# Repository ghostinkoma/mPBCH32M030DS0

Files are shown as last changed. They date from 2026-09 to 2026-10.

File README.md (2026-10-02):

# mPBCH32M030DS0 — CH32M030 ユニバーサル・モータードライバ基板

WCH **CH32M030C8U7 (QFN48)** の **DIP-42 MCU モジュール** (ブレッドボード対応) と、差し替え式の **パワー段子基板 (MOSFET ×8)** の 2 枚構成です。
次のモータを駆動します。
USB-C から ESP32-C3 / Arduino のように書き込めて、**USB-PD 充電器 (9〜15V) だけでもモーターを回せます**。
内蔵の電流源・USB-PD・OPA/CMP を使い切る設計です ([内蔵機能の活用検討](docs/advanced_features.md))。

| 駆動対象 | 使うハーフブリッジ | 子基板の出力 | JP5 (子基板) |
|---|---|---|---|
| 3 相モータ (BLDC/PMSM, ホール or センサレス) | HB0〜HB2 (TIM1) | U=OUT0, V=OUT1, W=OUT2 | 1-2 (センサレス 6 ステップは JP7=2-3) |
| フルブリッジ DC ×1 | HB0/HB1 (TIM1) | OUT0-OUT1 | — |
| フルブリッジ DC ×2 | + HB2/HB3 (TIM2) | OUT0-OUT1 と OUT2-OUT3 | 2-3 |
| バイポーラ・ステッピング | A = HB0/HB1, B = HB2/HB3 | A+=OUT0 A-=OUT1 B+=OUT2 B-=OUT3 | 2-3 |

> **ステータス: Rev 0.4 — 回路図 + 2 層基板レイアウト (未試作。全基板の配線完了)**。無保証です (LICENSE)。
> モーター駆動は大電流を扱います。電流制限付き電源で段階的に確認してください。

## Rev 0.4: DIP-42 MCU モジュール + パワー段子基板

- **MCU モジュール** (22.86 × 53.34mm = 2.54mm ピッチで **9 × 21 マス**, 2 層):
  - 左右の端に 1x21 ピンヘッダ ×2 (列間 17.78mm = 0.7in, Raspberry Pi Pico と同じ)。**ブレッドボード (82 × 52mm 等) にそのまま挿せます**。
  - ピンヘッダは **BOTTOM 面に実装し, ピンは MCU と反対側 (下) へ出します**。ブレッドボードや子基板のソケットに挿しても
    USB-C・ボタン・LED が上を向き, USB ケーブルの抜き差しとボタン操作ができます。
    ピン番号は TOP 面 (MCU 側) の外縁, 信号名は BOTTOM 面のシルクに印字しています。
  - USB-C は上端。RESET / USER・BOOT ボタン、センシング選択ジャンパ、**LED (電源 ×3・状態・ゲート ON ×8) はすべてモジュール上面**です。
  - 電圧に依存する部品 (TVS・VBUS 分圧・バルク容量・相電圧分圧) は子基板側にあり、モジュールは共通です。
- **パワー段子基板** A / B / C: 上面の 1x21 ピンソケット ×2 (モジュールと同じ位置・同じピン番号) にモジュールを上から挿します。
  - 左右 2 列のピンで支えるので、嵌合は**左右対称**です (Rev 0.3 の片寄った基板間コネクタによる傾き・接触不良を解消)。
  - MOSFET・シャントなどは子基板の下面 (ヒートシンク側)。LED は置いていません。
  - A/C は下端に電源入力 J3 (2x6) とモータ出力 J4 (2x8)。B は電源 2 本と 4 相出力を **M3 丸端子用の端子台** で受けます。
- 基板面積は Rev 0.3 (60 × 42mm = 2520mm²) に対し、モジュール 1219mm² (**−52%**)、子基板 A/C 1712mm² (**−32%**)、
  子基板 B は丸端子台とヒートシンク固定穴を載せるため 44.6 × 99.5mm (4438mm²) に広げました。
- Rev 0.3 の子基板 D (ピン引き出し) は廃止しました。モジュール単体をブレッドボードに挿せば、全信号にアクセスできます。
- コネクタは USB-C 以外すべて 2.54mm ピンヘッダ、コンデンサは入手性を確認した量産品 (1005〜1206) です。
  構成・寸法・品番の詳細は **[docs/stacking.md](docs/stacking.md)** にあります。

| 子基板 | MOSFET | 寸法 | 用途 |
|---|---|---|---|
| **A** | TPN1R603PL ×8 (30V 1.6mΩ) | 22.86 × 74.9mm | 標準。8〜16V, 約 5A/相 (電源ベタにはんだ盛り 0.3mm で) |
| **B** | TKR74F04PB ×8 (40V 0.74mΩ, TO-220SM(W)) | 44.6 × 99.5mm | **24V 系**, M3 丸端子台 ×6, ヒートシンク固定穴 ×2。`make POWER_STAGE=B`。約 5A/相 (1oz) / **約 7A/相** (はんだ盛り 0.3mm) |
| **C** | MTN2306AN3 ×8 (30V SOT-23) | 22.86 × 74.9mm | 廉価版。約 3A/相 |

| モジュール TOP | モジュール BOTTOM (裏から見た図) | 子基板 A TOP | 子基板 A BOTTOM |
|---|---|---|---|
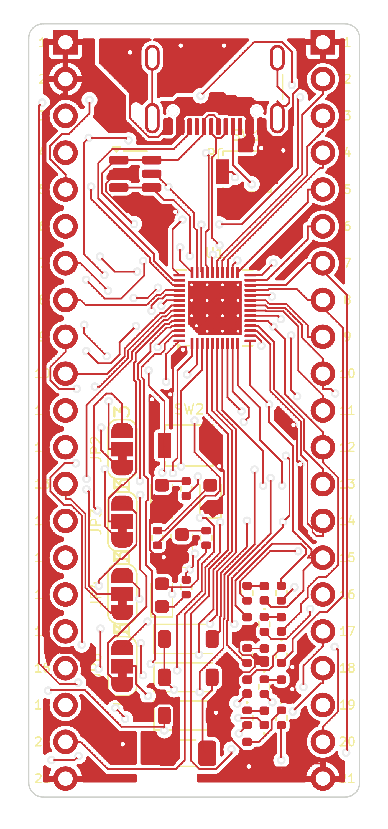
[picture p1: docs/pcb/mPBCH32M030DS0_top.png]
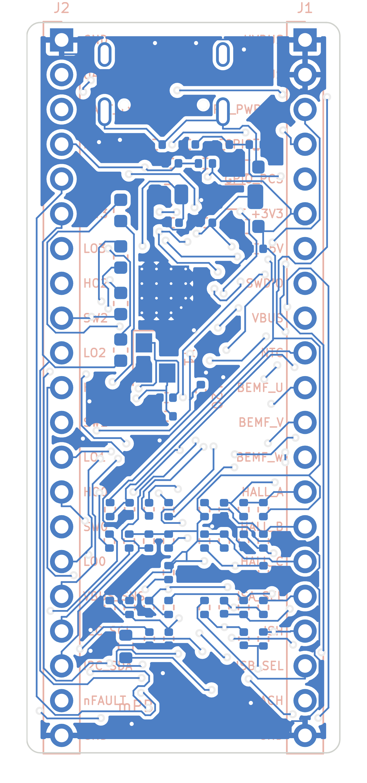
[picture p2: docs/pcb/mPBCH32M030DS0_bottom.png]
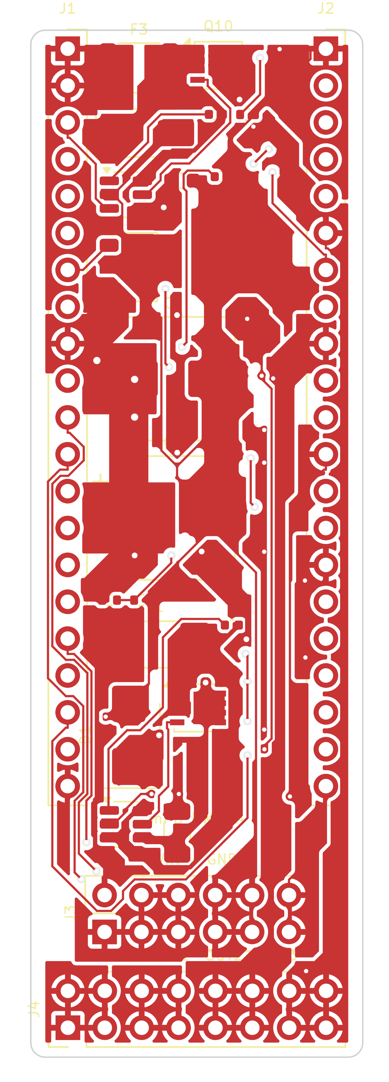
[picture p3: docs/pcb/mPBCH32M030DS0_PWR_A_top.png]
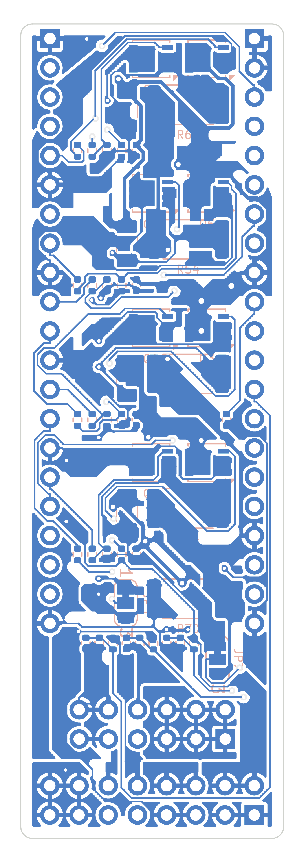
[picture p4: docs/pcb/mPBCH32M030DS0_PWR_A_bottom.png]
|  |  |  |  |

### モジュールのピン配置 (上面から見て USB-C が上, 子基板のソケット J1/J2 も同じ)

| ピン | J1 (左列) | J2 (右列) |
|---|---|---|
| 1 | USB_VBUS | GND |
| 2 | USB_VBUS | UART_RX |
| 3 | PD_PWR_EN | UART_TX |
| 4 | GPIO_PC4 | nRST |
| 5 | GPIO_PC5 | HO3 |
| 6 | +3V3 | SW3 |
| 7 | +5V | LO3 |
| 8 | SWDIO | HO2 |
| 9 | VBUS | SW2 |
| 10 | NTC | LO2 |
| 11 | BEMF_U | HO1 |
| 12 | BEMF_V | SW1 |
| 13 | BEMF_W | LO1 |
| 14 | HALL_A_IN | HO0 |
| 15 | HALL_B_IN | SW0 |
| 16 | HALL_C_IN | LO0 |
| 17 | ISA_SEL | VBUS_SNS |
| 18 | ISH | I2C_SCL |
| 19 | ISB_SEL | I2C_SDA |
| 20 | TACH_IN | nFAULT_IN |
| 21 | GND | GND |

- **ブレッドボード単体で使う場合**: USB-C から給電すると MCU・書き込み・USB は動作します (VHV ≈ 4.5V)。
  モータを回すときは VBUS ピン (≥ 8V) に外部電源と、HO/LO/SW に外付けのパワー段をつなぎます。
  VBUS_SNS (J2-17, VBUS 監視) には外付けで分圧 (≤ 3.3V) を入れてください (子基板では R11/R12)。
- +5V ピンは子基板の 78L05 から供給されます (ホールセンサ用)。単体で使うときは必要に応じて外部から 5V を入れます。
- HOx / LOx はゲート駆動出力 (VB/VDD8 振幅)、SWx は各相出力でブートストラップの帰路 (VSx) を兼ねます。

## 基板の幅 (9 マス) と配線

- MCU モジュールは 22.86mm 幅 (**9 マス**)、端子列の間隔は 17.78mm (0.7in, Raspberry Pi Pico と同じ列間隔) です。
  以前は 20.32mm 幅 (8 マス, 列間 0.6in) 版もありましたが、JLCPCB の 2 層標準 (最小線幅・間隙 0.127mm) では
  配線しきれず (0.10mm なら通るが 2 層では発注不可)、**9 マス版に一本化**しました。
- 水晶 Y1 と負荷容量 C131/C132 は QFN 下辺の XI/XO (8/9 番ピン) 直下の裏面に置き、表の下辺ピン 1〜7 の引き出しを空けています。
- 全基板 2 層・線幅・間隙 0.127mm / ビア 0.6mm (穴 0.3mm) で**未接続 0 / 電気的 DRC エラー 0**。
- `hardware/nopour/` は、モジュールの配線とビアを残して GND ベタ・大電流の太らせたベタ (とベタへ落とすだけの
  スティッチングビア) を外した手直し用です。手直ししたら KiCad でベタ (GND 両面) を引き直してください。
- ベタは全基板で基板端から 1.0mm 離しています (ミシン目で割っても銅が出ないように)。
- **発注用パネル**: モジュール + 子基板 A / B / C を 1 枚 (99.9 × 99.8mm) にミシン目で面付けしたデータ `hardware/fab/mPBCH32M030DS0_panel.zip` (生成 `python3 gen_panel.py`, 詳細は [docs/stacking.md](docs/stacking.md#発注用パネル-ミシン目-4-種-1-枚))。
- 再生成: `python3 gen_pcb.py all` (配線まで)、`python3 gen_pcb.py nopour` / `fab` / `summary`。

## リポジトリ構成

| パス | 内容 |
|---|---|
| `hardware/mPBCH32M030DS0.kicad_sch` / `.kicad_pcb` | **MCU モジュール**: KiCad 回路図 (電源 / USB・水晶・リセット / MCU / I/O) と 2 層基板 |
| `hardware/daughter/PWR_A〜C/` | **パワー段子基板 A〜C**: 各 KiCad プロジェクト (回路図・基板・部品表) |
| `hardware/nopour/` | モジュールのベタなし版 (手直し用, 上の「基板の幅 (9 マス) と配線」) |
| `hardware/lib/` | フットプリント (`CH32M030DS0_QFN48`: 作業途中データから抽出, `mPB`: NANO2 ヒューズ) とシンボル `mdrv.kicad_sym` |
| `hardware/gen_schematic.py` | 回路図の生成元 (回路の正)。`verify_netlist.py` で KiCad の解釈と照合 |
| `hardware/fab/*.zip` | 製造データ (ガーバー, ドリル, 両面の部品座標) — 4 基板分 |
| `hardware/bom.csv`, `hardware/daughter/*/bom.csv` | 部品表 (品番付き) |
| `hardware/wip/` | 作業途中の元データ (KiCad 8)。レビュー結果は [docs/design.md §3](docs/design.md#3-作業途中データ-hardwarewip-のレビュー結果) |
| `docs/schematic.pdf`, `docs/schematic_PWR_A〜C.pdf` | 回路図 PDF |
| `docs/pcb/` | 基板図 (TOP / BOTTOM, SVG・PNG) と DRC 結果 |
| `docs/stacking.md` | **モジュールと子基板の構成・寸法・レイアウト・コンデンサ品番** |
| `docs/design.md` | **部品選定の妥当性と設計根拠** (データシート値) |
| `docs/advanced_features.md` | 内蔵機能 (電流源/シンク・USB-PD・OPA/CMP 全モード) の活用検討 |
| `firmware/bootloader/` | USB/UART ブートローダ (WCH IAP 互換, 20KB) |
| `firmware/core/`, `firmware/lib/` | スケッチ環境 (ch32fun 風): 起動・USB 書き込み・PD と, モーター / I2C / ログ / WS2812 / LED (CIE, RGBW) / センサ / エンコーダ / 保護出力 / OLED・HT16K33・TM1640 表示のライブラリ。**[firmware/README.md](firmware/README.md)** |
| `firmware/app_template/` | Arduino 風テンプレート (`setup()` / `loop()`)。全プロジェクト共通の `src/config.h` + `src/sketch.c`。`firmware/tools/new_sketch.py` で作る |
| `firmware/examples/` | サンプル 13 本 (DC / ステッピング / 3 相 ホール・センサなし, I2C マスタ・スレーブ, UART ログ, WS2812, LED の CIE 調光, **RGBW 4ch (エンコーダ + WS2812 入力), 保護出力, FreeRTOS + OLED/HT16K33/TM1640**) |
| `arduino/` | **Arduino Boards Manager 用パッケージ** (boards.txt / platform.txt / mpbfun ライブラリ) と作成スクリプト。**[arduino/README.md](arduino/README.md)** |
| `package_mpbch32m030_index.json` | Boards Manager の索引 (GitHub Actions が作って置く) |
| `.github/workflows/arduino-package.yml` | コアのアーカイブ作成, ツールチェーン (xPack riscv-none-elf-gcc) の Releases へのミラー, 全サンプルのビルド確認 |
| `tools/mpb_upload.py` | 書き込みツール (USB / UART, Windows・macOS・Linux) |

KiCad ファイルは **KiCad 8 形式** (回路図 20231120, 基板は pcbnew 8.0 で生成) です。再生成の手順 (KiCad 8.0.x の Python が必要):

```bash
cd hardware
python3 gen_schematic.py                       # 回路図 4 プロジェクト + parts.json
python3 gen_pcb.py all                         # 配置 → Freerouting → ベタ → 補修 → DRC (配置が同じなら前回の配線 build/*.ses を再利用)
python3 gen_pcb.py fab                         # 製造データ hardware/fab/*.zip
```

## 仕様

- 入力: **子基板 J3 (A/C: 2x6 ピンヘッダ / B: M3 丸端子台 J3 VIN・J5 GND) 8〜16V (公称 12V, 子基板 B は 24V 系)** / **USB-C PD 9〜15V (≤5A)**。
  理想ダイオード OR なので同時接続しても安全です。USB 5V のみでも MCU と書き込みは動作します
- 出力: 4 ハーフブリッジ (A/C: 子基板 J4, 各 4 ピン並列 / B: M3 丸端子台 J40〜J43), 連続電流は子基板による (A 約 5A/相, C 約 3A/相, B 約 7A/相), PWM 16〜20kHz
- MCU: CH32M030C8U7, RISC-V 72MHz, 8MHz 水晶
- 保護:
  - 逆接続・逆流 (理想ダイオード), 10A ヒューズ, TVS
  - ハードウェア過電流遮断 (25.4A / DAC 可変), 過電圧リセット (18V / 24V 系 28.5V)
  - VHV 27V クランプ, 過熱, 結線自己診断
- インターフェース: USB-C (USB2.0 FS + PD シンク), I2C, UART, 1 線 SDI, GPIO ×2 + タコ入力 + nFAULT, ホール ×3 (すべてモジュールの DIP ピン)
- センシング: 電流 3ch, センサレス BEMF (CMP3 + 内部仮想中性点), ホール XOR (TIM2), タコ / 電流リップル (QII1 → TIM3), NTC (子基板)

## 結線まとめ (ご要望の項目)

### USB Type-C (J8, GCT USB4105) — PD と D+/D-

| J8 ピン | ネット | 接続先 |
|---|---|---|
| A4/A9/B4/B9 VBUS | USB_VBUS | F2 (PTC 0.5A) → D6 → VHV (MCU 電源)<br>**F3 5A → U5 LM74700 + Q10 → VBUS (モーター電源, PD 契約後に PC3 で許可)**<br>120k/10k → **PA2 (USB VBUS 監視)** |
| A5 CC1 / B5 CC2 | USB_CC1 / USB_CC2 | **PA0 (CC1R) / PA1 (CC2R)** = PD0: Type-C Rd 5.1kΩ 内蔵。**PD シンクとして 8〜15V の固定 PDO を交渉** (`Mpb_PD_*`) |
| A6/B6 D+ | USB_DP | U3 IO1 (ESD, 基準 +3V3) → **PB0 (UDP)** |
| A7/B7 D- | USB_DN | U3 IO2 → **PB1 (UDM)** |
| A1/A12/B1/B12 GND | GND | |
| S1 シールド | USB_SHIELD | 1MΩ ‖ 4.7nF → GND |
| A8/B8 SBU | — | 未接続 |

### リセット / 操作

| 部品 | 接続 | 備考 |
|---|---|---|
| SW1 RESET | PC0 (RST) — 10k プルアップ + 0.1µF | RST ピンはオプションバイトで有効化 (RST_PIN_SEL=0) |
| SW2 USER/BOOT | PC4 — 10k プルアップ | 押しながらリセット → ブートローダ。**状態 LED D3 と共用** (PC4 Low で点灯) |

### 電源供給端子・ピンヘッダの配置 (Rev 0.4)

| 端子 | 基板 / 位置 | 内容 |
|---|---|---|
| **J3** PWR IN (2x6) | 子基板 下端 | 1〜6 VIN / 7〜12 GND (6 本並列) → F1 10A → Q9/U4 理想ダイオード → VBUS |
| **J4** MOTOR OUT (2x8) | 子基板 最下端 | 1〜4 OUT0, 5〜8 OUT1, 9〜12 OUT2, 13〜16 OUT3 (各 4 本並列) |
| J8 USB-C (PD 9〜15V) | モジュール 上端 | USB_VBUS (J1-1/2) → 子基板の F3 → U5+Q10 → VBUS (PD 契約後に PD_PWR_EN で許可) |
| J1 / J2 (1x21 ×2) | モジュール 左右端 | 全信号 ([ピン配置](#モジュールのピン配置-上面から見て-usb-c-が上-子基板のソケット-j1j2-も同じ))。UART / SDI (SWDIO, nRST) / I2C / ホール / GPIO もここから |

### 電源確認 LED / ゲート確認 LED (すべてモジュール上面)

| LED | 接続 | 意味 |
|---|---|---|
| D7 赤 | VBUS – 15k | モータ電源あり |
| D2 緑 | +5V – 2.2k | 5V (子基板の 78L05) |
| **D8 緑** | **+3V3 (VDD33) – 1.5k** | **MCU 電源 (内蔵 LDO 出力)** |
| D3 緑 | +3V3 – LED – 1k – PC4 (Low で点灯) | 状態 (ブートローダ中は高速点滅, PD 給電中も速い点滅) |
| **D10〜D17** (1005) | 各 HB の **HOx–SWx (H)** / **LOx–GND (L)** – 22k | **ゲート ON 表示** (PWM デューティで明るさが変わる)。子基板はヒートシンクで隠れるため、Rev 0.4 でモジュール側へ移動 |

### シャント抵抗による電流測定 (内蔵 ADC)

| チャネル | シャント | 経路 → ADC |
|---|---|---|
| IA | R34 10mΩ (HB0, 子基板) | JP7 (子基板) → J1-17 ISA_SEL → ISP1/ISN1 → OPA3 (差動, ゲイン 4/8/16/55) → **ADC IN9** |
| IB | R44 (HB1) / R54 (HB2) を子基板の JP5 で選択 | J1-19 ISB_SEL → ISP2/ISN2 → OPA4 → **ADC IN10** |
| IBUS | R70 10mΩ (全レッグの帰路, 子基板) | J1-18 ISH → R13/C17 → PB3 → **ADC IN1** (直接) + CMP3 → TIM1 ブレーキ |

電圧: VBUS (PB4, IN17), USB VBUS (PA2, IN15), 相電圧 U/V (PA5/PA7), 温度 NTC (PA4, ISOURCE1, NTC 本体は子基板の MOSFET 近傍)。
IA は JP7 で HB0 レッグ / バス電流を切り替えられ、CMP2 + 内蔵 DAC でサイクル毎の電流制限にも使えます。詳細は [docs/design.md §2.3](docs/design.md#23-電流電圧の計測-内蔵-adc)。

### 水晶

Y1 8MHz (3225, CL=20pF) — **PB5 (XI) / PB6 (XO)**, 30pF ×2 → GND。帰還抵抗は内蔵。

| ピン | 機能 |
|---|---|
| PC4 (J1-4) | GPIO / TIM1_CH2_3 / SPI_MISO (USER/BOOT ボタン + 状態 LED 兼用, 例: DIR) |
| PC5 (J1-5) | **HV I/O** (VHV 系, 入力耐圧 VHV+6V) — 12V 系の EN / リミットスイッチに |
| TACH_IN (J1-20) | R123 → JP8 → C105 → PA12 (QII1: OPA1 → CMP1 → TIM3 CH1)。ファン FG / VR センサ等の周期計測 |
| nFAULT (J2-20) | PA13 = TIM1_BKIN_1 (Low で全ゲート OFF) |

Rev 0.2 では PC3 (PD 給電許可) と PA6 (W 相センシング) を内蔵機能に割り当てたため、引き出し GPIO は減っています
(理由は [docs/advanced_features.md](docs/advanced_features.md))。ジャンパを外せば、JP2〜JP4 の中央ピン (PA5/PA6/PA7) も使えます。

## CH32M030C8U7 ピン割当 (QFN48)

| ピン | 名称 | 用途 | ピン | 名称 | 用途 |
|---|---|---|---|---|---|
| 1 | PA12 | QII_IN (OPA1→CMP1→TIM3) | 25 | PB15 | HO3 (TIM2_CH2) |
| 2 | PA13 | nFAULT (TIM1_BKIN_1) | 26 | VDD8 | 10µF+0.1µF |
| 3 | PA14 | I2C SDA (リマップ2) | 27 | PC0 | RST |
| 4 | PA15 | I2C SCL (リマップ2) | 28 | PC1 | UART TX |
| 5 | PB2 | OCP_REF (CMP3_N3) | 29 | PC2 | UART RX (リマップ1) |
| 6 | PB3 | IBUS (CMP3_P3, ADC1) | 30 | PC3 | PD_PWR_EN (USB 給電許可) |
| 7 | PB4 | VBUS 監視 / OVP | 31 | PC4 | USER/BOOT + 状態 LED, GPIO (J1-4) |
| 8 | PB5 | XI | 32 | PC5 | HV I/O (J1-5) |
| 9 | PB6 | XO | 33 | VDD33 | 4.7µF+0.1µF |
| 10 | PB8 | LO0 (TIM1_CH1N) | 34 | VHV | 10µF+0.1µF |
| 11/12 | VS0/VB0 | HB0 ブート | 35 | PA0 | USB CC1 |
| 13 | PB9 | HO0 (TIM1_CH1) | 36 | PA1 | USB CC2 |
| 14 | PB10 | LO1 (TIM1_CH2N) | 37 | PA2 | USB VBUS 監視 (ADC15) |
| 15/16 | VS1/VB1 | HB1 ブート | 38 | PA3 | SWDIO |
| 17 | PB11 | HO1 (TIM1_CH2) | 39 | PB0 | USB D+ |
| 18 | PB12 | LO2 (TIM1_CH3N / TIM2_CH1N) | 40 | PB1 | USB D- |
| 19/20 | VS2/VB2 | HB2 ブート | 41 | PA4 | NTC (ISOURCE1) |
| 21 | PB13 | HO2 (TIM1_CH3 / TIM2_CH1) | 42 | PA5 | SENS_U (ADC6) |
| 22 | PB14 | LO3 (TIM2_CH2N) | 43 | PA6 | SENS_W (CMP3_N1, TIM2_CH2) |
| 23/24 | VS3/VB3 | HB3 ブート | 44 | PA7 | SENS_V (ADC2) |
| | | | 45 | PA8 | ISN1 |
| | | | 46 | ISP1 | 電流 A |
| | | | 47 | PA10 | ISP2 電流 B |
| | | | 48 | PA11 | ISN2 |
| | | | EP (49) | GND | 裏面パッド |

## ブートローダとファームウェア書き込み (USB-C)

### 選定: WCH 公式 IAP を基板向けに改造したもの

CH32M030 は工場出荷のシステムブートローダ (USB ISP) を持たないため (RM 19.1 のメモリマップに BOOT 領域が無い)、
ユーザー領域の先頭 20KB にブートローダを置きます。WCH 公式 EVT の `UART_USB_IAP` (CH32M030 専用) を土台にしました。

| 比較 | WCH IAP 改 (採用) | 独自 USB DFU / CDC | ch32fun USB ブートローダ |
|---|---|---|---|
| CH32M030 対応 | ◎ 公式サンプルが専用 | 自作が必要 | ✕ 未対応 (CH32X035/CH570 のみ) |
| 実績・保守 | ◎ WCH 提供 | △ | — |
| ホストツール | 本リポジトリの `mpb_upload.py` (全 OS) + WCH 純正 WinAPP | dfu-util 等 | minichlink |
| サイズ | 5.7KB | — | — |

改造点: 起動条件 (アプリ無し / アプリからの要求 / USER・BOOT ボタン)、UART を PC1/PC2 へ、状態 LED 点滅、
USB bcdDevice でアプリ (0xA001) とブートローダ (0xB001) を区別。

**フラッシュ配置**: `0x08000000` ブートローダ (20KB) / `0x08005000` アプリ (44KB−128B) / `0x0800FF80` 要求フラグ

### 使い方 (Arduino / ESP32 と同じ流れ)

```bash
# 0) ツール (Ubuntu の例)
sudo apt install gcc-riscv64-unknown-elf picolibc-riscv64-unknown-elf libusb-1.0-0
pip install pyusb pyserial
sudo cp tools/99-mpb.rules /etc/udev/rules.d/    # root なしで USB を開く

# 1) SDK を取得してビルド
cd firmware && ./sdk/fetch_sdk.sh
make -C bootloader          # → bootloader/build/mpb_bootloader.hex
make -C app_template        # → app_template/build/app.bin
make                        # ブートローダ + テンプレート + サンプル全部 (make test で単体テスト)

# 2) 【初回のみ】ブートローダを WCH-LinkE (1 線 SDI: J1-8 SWDIO / J2-4 nRST / GND) で書き込む
#    子基板 J3 (またはモジュールの VBUS ピン) に 12V を給電 (SWD には VHV ≥ 5V が必要)。WCH-Link から 3.3V は供給しない。
#    WCH-LinkUtility (Windows) か MounRiver Studio で mpb_bootloader.hex を 0x08000000 へ
#    (wlink が CH32M030 に対応していれば: make -C bootloader flash)

# 3) 以降は USB-C だけで書き込み (アプリ実行中でも自動でブートローダへ切り替わる)
make -C app_template upload
#    = python3 tools/mpb_upload.py app_template/build/app.bin
```

- スケッチは `firmware/app_template/src/sketch.c` の `setup()` / `loop()` に書く (Arduino の .ino 相当)。
  ライブラリとサンプルの説明は [firmware/README.md](firmware/README.md)。サンプルは `make -C examples/dc_motor upload` のように書き込む。
- `main.c` が USB/UART の書き込み要求を常に受け付けるので、「Upload」だけで書き換わる (ESP32 / Arduino の自動リセット相当)。
- アプリが暴走して応答しない時は **SW2 (USER/BOOT) を押しながら SW1 (RESET)** → 状態 LED が高速点滅 → 書き込み可能。
- USB だけの給電でも MCU とブートローダは動作する (VHV ≈ 4.5V)。モーター駆動には子基板 J3 の 12V か、PD 充電器 (9〜15V) が必要。
- Windows: pyusb 用に Zadig で WinUSB を 1A86:55E0 に割り当てる。WCH 純正の `WCHMcuIAP_WinAPP.exe` も同じプロトコルで使える。
- UART 書き込み: `python3 tools/mpb_upload.py --uart COM3 app.bin` (J2-3 TX / J2-2 RX, 460800bps, 先に BOOT ボタンでブートローダを起動)。

### 検証状況

| 項目 | 状態 |
|---|---|
| 回路図の接続 | `kicad-cli` のネットリストと設計値が一致 (`verify_netlist.py`): **モジュール 83/83, 子基板 A/B/C 58/58** (KiCad 8.0.9) |
| モジュールと子基板の嵌合 | モジュール J1/J2 と子基板 J1/J2 は同じ座標・同じピン番号・同じネット名 (回路図生成時に同じピン表から作成) |
| 基板 (2 層) | **子基板 A/B/C: 未接続 0 / 電気的 DRC エラー 0** (シルクの重なり等の警告のみ)。**MCU モジュール: 未接続 0 / 電気的 DRC エラー 0** ([docs/stacking.md](docs/stacking.md#mcu-モジュールの配線))。製造データ (ガーバー・ドリル・部品座標) は `hardware/fab/*.zip` |
| ブートローダ / アプリ | GCC 13 (riscv64-unknown-elf + picolibc) で**警告 0 でビルド** (5.7KB / 10.6KB, サンプル 10〜22KB, FreeRTOS 版 35KB / 44KB)。`POWER_STAGE=A/B` の両方を確認 |
| Arduino パッケージ | arduino-cli 1.3.1 で, 索引から**コアとツールのインストール → 全 12 サンプルのビルド**まで確認 (ツールチェーンは手元の GCC 13 で代用) |
| ライブラリの計算 | ホストの単体テスト (`make -C firmware test`): 書式化, CIE 1931, センサ換算 (BMP280・SHT3x のデータシート例題と一致), ステッピングの加減速と位置決め, DC モーターの停止・回生 (モーター + 母線のモデル) |
| 書き込みツール | ブートローダのプロトコル処理を Python で再現したシミュレータで**書込・検証が一致** (`tools/test_mpb_upload.py`) |
| 実機 | **未確認** (基板未製作) |

## ファームウェア開発の注意

- TIM1 (HB0〜HB2) と TIM2 (HB2/HB3 リマップ2) を同時に同じピンへ出さないこと (PB12/PB13 は両方の候補)。
- デッドタイム初期値 0.5µs, PWM 16〜20kHz から始め、ゲート確認 LED とオシロで確認する。
- 過電流: CMP3 (IBUS) / CMP2 (OPA3+DAC) の割込み (`OPA_IRQHandler`) で全レッグのゲートを Low に固定する。TIM1 BKIN のハード遮断も使えるが,
  BKIN の既定端子 PA15 は I2C の SCL と共用なので, I2C と併用するときは `Mpb_BridgeCfg.hw_break = 0` (既定)。
- ゲート駆動電源 VDD8 はリセット時 5V。`Mpb_Bridge_Init()` とモーターの `*_Task()` が VBUS に合わせて自動で選ぶ (VBUS ≥ 12V → 10V)。
- パワー段 (子基板) に合わせて `make POWER_STAGE=A|B|C` でビルドする (B は VBUS 分圧比 1/19)。子基板 B は Qg が大きいので
  `8 × Qg × fPWM + MCU ≤ 35mA` (VDD8 LDO) を満たす PWM 周波数にする。
- ゲートを駆動する前に VBUS ≥ 8V を ADC で確認する (USB のみ給電時は駆動しない)。
- `loop()` は Delay で止めない (USB-PD の処理は 1ms 周期で `Mpb_PD_Task()` を呼ぶ必要がある)。
- 起動時に `Mpb_SelfTest_Wiring()` でモーターの接続を確認してからパワー段を有効にすると安全。
- ウォッチドッグ (WWDG) は常に有効: ハング・設定異常・故障・リセットのどの経路でも全 FET OFF にし, 上下短絡にはしない ([firmware/README.md](firmware/README.md#ウォッチドッグと全-fet-offcorempb_wdtc-常に有効))。

## ライセンス

- **個人利用は自由 (クレジット表示必須)**: 「mPBCH32M030DS0 by ghostinkoma」とリポジトリ URL を表示
- **商用利用は作者へ連絡**: sinhex.k@gmail.com
- **一切無保証**
- 詳細は [LICENSE](LICENSE)、第三者の著作物 (WCH SDK 由来コード等) は [NOTICE](NOTICE)

## 参考

- WCH CH32M030 データシート / リファレンスマニュアル: https://www.wch-ic.com/products/CH32M030.html
- WCH 公式 EVT (SDK, IAP サンプル, 評価ボード回路図): https://github.com/openwch/ch32m030
- 東芝 TPN1R603PL: https://toshiba.semicon-storage.com/us/semiconductor/product/mosfets/12v-300v-mosfets/detail.TPN1R603PL.html
- 東芝 TKR74F04PB (子基板 B): https://toshiba.semicon-storage.com/us/semiconductor/product/mosfets/12v-300v-mosfets/detail.TKR74F04PB.html
- 東芝 TPN2R304PL (理想ダイオード Q9, 40V): https://toshiba.semicon-storage.com/us/product/mosfet/detail.TPN2R304PL.html
- Cystech MTN2306AN3 (子基板 C): https://www.alldatasheet.net/datasheet-pdf/marking/330821/CYSTEKEC/MTN2306AN3.html
- Freerouting (自動配線): https://github.com/freerouting/freerouting

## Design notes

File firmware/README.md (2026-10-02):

# mPBCH32M030DS0 ファームウェア — スケッチ環境 (mpbfun)

`setup()` / `loop()` を書くだけで使える, ch32fun 風の小さな環境です。
モーター制御・I2C・UART ログ・WS2812・LED 調光・センサ・エンコーダを, **どれも待たない (delay を使わない) API** で揃えています。

> **実機では未確認です** (基板未製作)。ビルドは GCC 13 で警告 0, 計算部分はホスト (PC) の単体テストで確認しています。
> モーターを回す前に, 必ず電流制限付きの電源で, ゲート確認 LED とオシロで波形を確かめてください。

## 構成

```
firmware/
├── common/            ボード定義 (board.h), リンカスクリプト, ビルドルール (rules.mk / app.mk)
├── core/              常にリンクされる土台: 起動, USB/UART 書き込み要求, USB-PD, mpb.h (ADC・電流アンプ・過電流・タコ・NTC)
├── lib/               機能ライブラリ (アーカイブにして, スケッチが使った物だけリンク)
│   └── mpbfun.h       これ 1 つを include すれば全部使える
├── app_template/      自分のスケッチの出発点 (src/config.h + src/sketch.c)
├── examples/          サンプル 13 本 (各ディレクトリで make / make upload)
├── tools/new_sketch.py  新しいスケッチを雛形から作る (config.h 付き)
├── tools/mpb.py       SDK のコマンド (build / upload / monitor / compdb …)。VS Code のタスクが呼ぶ
├── .vscode/           VS Code のワークスペース設定 (タスク, clangd, デバッグ)
├── tests/             ホスト (PC) で動く単体テスト
├── bootloader/        USB/UART ブートローダ (最初の 1 回だけ WCH-LinkE で書く)
└── sdk/               WCH 公式 SDK (./sdk/fetch_sdk.sh で取得)
```

## ビルドと書き込み

```bash
# ツール (Ubuntu の例)
sudo apt install gcc-riscv64-unknown-elf picolibc-riscv64-unknown-elf
cd firmware && ./sdk/fetch_sdk.sh

make                              # ブートローダ + テンプレート + 全サンプル
make test                         # 単体テスト (実機不要)
make -C examples/dc_motor upload  # サンプルを USB-C で書き込む
make -C app_template POWER_STAGE=B upload   # 子基板 B (24V 系) 用
```

- 自分のスケッチは `python3 tools/new_sketch.py ../my_app` で作ります (`--from stepper` でサンプルから, `--rtos` で FreeRTOS 版)。
  全プロジェクト (テンプレート・サンプル) が同じ形: `Makefile` (2〜3 行) + `src/config.h` + `src/sketch.c`。

  ```make
  TARGET := app
  include ../../common/app.mk        # ディレクトリの深さに合わせる (new_sketch.py が合わせる)
  ```
- `src/` に置いた `.c` は全部リンクされます。
- **Arduino IDE** でも使えます (Boards Manager, FreeRTOS も可): [../arduino/README.md](../arduino/README.md)。

### エディタ (VS Code) で使う

`firmware/` を VS Code で開くと, 設定済みのワークスペース (`firmware/.vscode/`) が使えます。
推奨拡張機能 (clangd, C/C++, Serial Monitor) を入れてください。開いているファイルのプロジェクトが対象になります。

| 操作 | 内容 |
|---|---|
| Ctrl+Shift+B (`mpb: build`) | ビルド + `compile_commands.json` 作成 (clangd がビルドと同じ設定で補完・定義ジャンプ・エラー表示) + 使用量 |
| タスク `mpb: upload (USB-C)` | ビルドして書き込み |
| タスク `mpb: serial monitor` | UART ログ (460800bps) |
| タスク `mpb: new sketch` | サンプルから新しいスケッチ (config.h 付き) を作る |
| F5 `mpb: debug (WCH-LinkE)` | WCH 版 OpenOCD + gdb でデバッグ (**未検証**: MounRiver 同梱の OpenOCD が必要) |

中身は `tools/mpb.py` (build / upload / clean / compdb / new / monitor / size / list) で, 端末からも同じことができます。
- コンパイラ: 汎用 GCC (`riscv64-unknown-elf-`, 既定) / xPack・MounRiver GCC (`make PREFIX=riscv-none-elf- LIBC_SPECS="--specs=nano.specs --specs=nosys.specs"`) /
  WCH GCC の高速割込み (`make IRQ=wch PREFIX=riscv-wch-elf-`)。
- MounRiver Studio で使う場合は「Makefile プロジェクト」として `firmware/` を開き, ビルドコマンドに上の `make` を指定します
  (SDK のサンプルと同じ WCH GCC で, 割込みは `IRQ=wch`)。IDE 独自のプロジェクト生成は不要です。

## スケッチの書き方

### src/config.h (全プロジェクト共通の雛形)

`src/config.h` はスケッチだけでなく **core / lib / SDK を含む全ソースの先頭で読み込まれます** (`-include`)。
ボード (`MPB_POWER_STAGE` 子基板, `MPB_UART_BOOT` UART 書き込み, `MPB_UART_BAUD`), ライブラリ (`MPB_LOG_BUF`, `MPB_WS2812_MAX`, `MPB_DEBUG` …),
スケッチの定数 (`CFG_*`: PWM 周波数, ピン, 電流 …) をここにまとめます。`#define` だけを書き, 変えると全部作り直されます。
ステッピングモーターの代表的な形式ごとの設定値 (NEMA17/14/23, PM 型, 28BYJ-48) は `examples/stepper/src/config.h` のコメントにあります。

### sketch.c

```c
#include "config.h"
#include "mpbfun.h"

void setup(void)
{
    Mpb_Time_Init();                 /* µs / ms の時計 (TIM3) — 最初に呼ぶ */
    Mpb_Log_Init(0);                 /* UART ログ (J2-3, 460800bps) */
    ...
}

void loop(void)
{
    Mpb_Dc_Task();                   /* 使うモジュールの *_Task() を毎回呼ぶ */
    MPB_EVERY_MS(t, 200) { MPB_LOGI("I %d mA", Mpb_Dc_Current_mA(0)); }
}
```

- **loop() を止めないこと**。どの関数も待たずに戻り, 時間のかかる処理は `*_Task()` が少しずつ進めます
  (USB-PD の処理も 1ms 周期で回す必要があります)。
- 周期処理は `MPB_EVERY_MS(変数名, ms) { … }`。時刻は `Mpb_Millis()` / `Mpb_Micros()`。
- 例外として短い待ちが 2 つあります: ADC の単発変換 (約 4µs) と, WS2812 の送信 (LED 1 個 30µs, 送信中は割込み停止)。

## ライブラリ一覧

| ヘッダ | 内容 | 主な関数 |
|---|---|---|
| `mpb.h` (core) | 時間, ADC, VBUS, 電流アンプ, 過電流, ホール / BEMF, タコ (QII), NTC, USB-PD | `Mpb_Millis` `Mpb_Vbus_mV` `Mpb_Ocp_*` `Mpb_Tach_PeriodUs` `Mpb_Ntc_DeciCelsius` `Mpb_PD_*` |
| `mpb_bridge.h` | 4 本のハーフブリッジ: 中心揃えの相補 PWM + デッドタイム (TIM1 と TIM2 を同期), ゲート電源 VDD8 の自動選択, **PWM の山で IA/IB を同時に取り込む電流計測**, ローサイドだけの PWM | `Mpb_Bridge_Init` `Mpb_Bridge_Leg` `Mpb_Bridge_LegLow` `Mpb_Bridge_CurrentInit` `Mpb_Bridge_Current_mA` |
| `mpb_dc.h` | DC モーター ×2: 正転 / 逆転, duty (加減速付き) または **電流制御 (PI)**, 電流制限, **停止 (回生 → 短絡 → 保持 → 惰性, VBUS 監視付き)**, **Kv [rpm/V] からの回転数の概算** | `Mpb_Dc_SetDuty` `Mpb_Dc_SetCurrent` `Mpb_Dc_Stop` `Mpb_Dc_Rpm` |
| `mpb_stepper.h` | 2 相バイポーラ: フル〜**1/128 マイクロステップ** (sin 表はフラッシュ 258 バイト), 正転 / 逆転, 台形加減速, 位置決め, 保持電流, **ソフトウェア タコ** | `Mpb_Stepper_SetRpm` `Mpb_Stepper_MoveTo` `Mpb_Stepper_Rpm` |
| `mpb_bldc.h` | 3 相ブラシレス 6 ステップ: **ホールセンサ** (エッジで転流 + 周期でタコ) / **センサなしのオープンループ** (V/f), 正転 / 逆転, 電流制限, 外部タコ (TACH_IN) | `Mpb_Bldc_SetDuty` `Mpb_Bldc_SetRpm` `Mpb_Bldc_Rpm` `Mpb_Bldc_TachRpm` |
| `mpb_led.h` + `mpb_cie.h` | パワー段 (MOSFET) につないだ単色 LED の **CIE 1931 L*** 調光, フェード, 呼吸 | `Mpb_Led_Fade` `Mpb_Led_Breathe` `Mpb_Cie` |
| `mpb_ws2812.h` | WS2812B / SK6812 (RGB/RGBW), HSV, L* での減光, 変化したときだけ送信 | `Mpb_Ws2812_Hsv` `Mpb_Ws2812_Show` |
| `mpb_encoder.h` | ロータリーエンコーダ (EXTI, 4 逓倍, チャタリング打ち消し) + ボタン (デバウンス, 長押し) | `Mpb_Enc_Delta` `Mpb_Enc_Pressed` |
| `mpb_i2c.h` | I2C マスタ (割込みなしのステートマシン, タイムアウトとバス復旧) | `Mpb_I2c_Start` `Mpb_I2c_Done` |
| `mpb_i2c_slave.h` | I2C スレーブ (レジスタマップ, 書き込み範囲の通知) | `Mpb_I2cSlave_Init` `Mpb_I2cSlave_Written` |
| `mpb_env.h` | 環境センサ: **SHT3x / AHT20 / BMP280・BME280 / S-5851A** (TinyWetherMemo と同じ種類) | `Mpb_Env_Init` `Mpb_Env_Task` |
| `mpb_log.h` | UART ログ (リングバッファ + 送信割込み), 整数の printf, 小数の表示 | `MPB_LOGI` `Mpb_Log_Printf` `Mpb_Log_Fixed` |
| `mpb_guard.h` | **保護出力**: 熱 (NTC) / 過電流 / 短絡 / 過電圧 / 低電圧で GPIO を High (既定 PC5)。短絡は割込み内で即時。ラッチ, ブリッジ停止 | `Mpb_Guard_Init` `Mpb_Guard_Task` `Mpb_Guard_Flags` |
| `mpb_rgbw.h` | パワー段 4ch で RGBW LED テープ: マスター明るさ (L*) × 色 (線形混色 / ch ごとの L*), HSV, フェード | `Mpb_Rgbw_SetMaster` `Mpb_Rgbw_SetHsv` `Mpb_Rgbw_SetLevels` |
| `mpb_wsrx.h` | **WS2812 互換の受信**: この基板を数珠つなぎの 1 画素にする (先頭 1 画素を受け, 残りを DOUT へ中継) | `Mpb_WsRx_Init` `Mpb_WsRx_Poll` |
| `mpb_oled.h` | I2C OLED (SSD1306 / SH1106, 128×64/32) の 21 桁 × 8 行テキスト + バー。変わった行だけ送る (RAM 約 300 バイト) | `Mpb_Oled_Printf` `Mpb_Oled_Bar` `Mpb_Oled_Task` |
| `mpb_matrix.h` | 8×8 マトリクスの数珠つなぎ用の描画 (2 色), 5×7 文字, 流れる文字 | `Mpb_Matrix_Print` `Mpb_Matrix_Marquee` |
| `mpb_ht16k33.h` | HT16K33(A) 8×8 マトリクス ×8 枚まで (I2C 0x70〜, 配線の違いは map で選ぶ) | `Mpb_Ht16k33_Init` `Mpb_Ht16k33_Task` |
| `mpb_tm1640.h` | TM1640 2 色 8×8 ×8 枚まで (SCLK 共有 + DIN 個別, 全枚を同時に送る)。ghostinkoma/TM1640MatrixChain の移植 | `Mpb_Tm1640_Init` `Mpb_Tm1640_Task` |

## サンプル

| ディレクトリ | 内容 | 配線 / ジャンパ |
|---|---|---|
| `examples/dc_motor` | DC モーターの正転 / 逆転。エンコーダで **回転数の目安 (Kv から逆算)** か **電流** を設定, 長押しで切り替え | OUT0–OUT1, JP7/JP5 = 1-2, エンコーダ = HALL_A/HALL_C (JP2/JP4 = 2-3) |
| `examples/stepper` | ステッピング 1/16 マイクロステップ。エンコーダで回転数 (±), 長押しで 1 回転の位置決め往復, 相電流とタコをログ | A = OUT0/OUT1, B = OUT2/OUT3, JP5 = 2-3 |
| `examples/bldc_hall` | 3 相 (ホール付き)。ボタンで duty と向きを切り替え, ホール周期と TACH_IN の 2 通りのタコ | U/V/W = OUT0〜2, JP2〜4 = 2-3 |
| `examples/bldc_open` | 3 相 (センサなし)。エンコーダで回転数 (±), 転流周期からのソフトウェア タコ | U/V/W = OUT0〜2 |
| `examples/i2c_sensors` | I2C マスタ。SHT3x / AHT20 / BMx280 / S-5851A を同じバスで読み, UART に出す | SDA = J2-19, SCL = J2-18, プルアップ R114/R115 |
| `examples/i2c_slave` | I2C スレーブ (0x30)。VBUS・温度・時刻を読み出し, LED の点灯方法を書き込める | 同上 |
| `examples/uart_log` | UART ログ。VBUS・USB 電圧・NTC 温度・PD の状態を 1 秒ごと | TX = J2-3 |
| `examples/ws2812` | WS2812 8 個: 虹色 / 呼吸 (L*), エンコーダで明るさ | DIN = J2-2 (PC2) |
| `examples/led_cie` | LED テープを OUT0 のローサイドで CIE 調光 (2kHz, 1/18000), フェードと呼吸 | LED + = VBUS, − = OUT0 |
| `examples/led_rgbw` | **RGBW 4ch LED (CIE 1931)**: エンコーダで明るさ / 色相 / 彩度 / 白 (長押しで切替, 押しで ON/OFF, 加速・勢い回し), **WS2812 互換入力**でも操作 (Ch32LightBox と同じ考え方) | R/G/B/W = OUT0〜3 (− 側), DIN = PC2, DOUT = PA14 |
| `examples/protect` | **保護出力**: 熱・過電流・短絡で PC5 を High (外部のリレー・ブザー・上位機器へ), ボタンで解除 | 負荷 = OUT0–OUT1, 警報 = PC5 (High = VHV なので注意) |
| `examples/rtos_motor_display` | **FreeRTOS**: ステッピングを回しながら OLED (状態 + バー), HT16K33 ×4 (rpm), TM1640 ×4 (流れる文字) に表示。タスク 4 本, 静的確保 (RAM 約 9KB) | I2C = J2-19/18, TM1640: SCLK = PA5, DIN = PA6/PA7/PC2/PC4 |

## 資源の割り当て (同時に使えない組み合わせに注意)

| 資源 | 使い道 |
|---|---|
| TIM1 | HB0〜HB2 の PWM, CH4 = ADC 注入変換の起動 (PWM の山) |
| TIM2 | HB2/HB3 の PWM (`use_tim2 = 1`: ステッピング, DC 2ch) **または** ホールセンサ I/F (`mpb_bldc` のホール) |
| TIM3 | 時計 (1µs) + TACH_IN の周期計測 (QII1 → CH1) |
| ADC | 通常変換 = `Mpb_Adc_Read` (VBUS・NTC など), 注入変換 = IA/IB (PWM 同期, `ADC_IRQHandler`) |
| USART1 | ログの送信 (PC1) + 書き込み要求の受信 (PC2) |
| I2C1 | マスタ **または** スレーブ (PA14 SDA / PA15 SCL) |
| EXTI | エンコーダ (既定 PA5/PA6) |
| SysTick | WS2812 の送受信中だけ HCLK で計時 (SDK の `Delay_*` も使う)。**FreeRTOS ではティック**: WS2812 / wsrx は使えず, `Delay_*` は TIM3 版に置き換わる |

| 端子 (モジュール) | 使い道 |
|---|---|
| PA5 / PA7 / PA6 (J1-14〜16 HALL_A/B/C, JP2〜4) | ホールセンサ, BEMF (1-2), エンコーダ (2-3 にしてプルアップと RC を使う) |
| PA14 / PA15 (J2-19 / J2-18) | I2C。**PA15 は TIM1 の BKIN 既定端子**なので, モーターと I2C を併用するときは `hw_break = 0` (既定) |
| PC1 / PC2 (J2-3 / J2-2) | UART TX / RX。WS2812 は PC2 を使う (UART からの書き込み要求は切る) |
| PC4 (J1-4) | 状態 LED + USER ボタン (共用, オープンドレイン)。TM1640 の DIN3 にも使える (オープンドレイン) |
| PC5 (J6) | 保護出力 (`mpb_guard` の既定)。**HV I/O: High = VHV (VBUS 系)** なので, 3.3V/5V の機器へは分圧かトランジスタを入れる |
| PA12 (J1-20 TACH_IN) | 外部タコ / FG (JP8 = 1-2), またはバス電流のリップル (2-3) |

## 電流の向きと計測

- シャントは各レッグのローサイドの帰路 (ソース → シャント → GND) にあり, アンプは **ソース → GND の向きを正** に測ります。
- PWM は中心揃えで, 山 (カウンタ = ARR) では全レッグのローサイドが ON です。ここで IA/IB を取り込むので,
  PWM している相も含めて相電流が得られます (デューティ上限 `max_duty`, 既定 90% はこの時間とブートストラップのため)。
- DC モーター (HB0/HB1): 正転の電流 = (IB − IA) / 2。ステッピング: コイル電流 = −IA / −IB。3 相: ローサイド ON の相の電流。
- 起動直後に全レッグ開放で 256 回平均してオフセットを取ります (`Mpb_Bridge_CurrentReady()` が 1 になるまで約 13ms)。

## 保護

- `Mpb_Ocp_BusCmp3_Init()` (バス 25.4A) と `Mpb_Ocp_Cmp2_Init()` (OPA3 + DAC, レッグごとの制限) がコンパレータで過電流を検出し,
  割込みで全レッグのゲートを Low に固定します (`Mpb_Bridge_Faulted()`, 解除は `Mpb_Bridge_ClearFault()`)。
- `hw_break = 1` にすると TIM1 のハードのブレーキ (BKIN) も使いますが, BKIN の既定端子 PA15 (I2C の SCL) を Low に固定します。
- ゲート駆動電源 VDD8 はリセット時 5V です。`Mpb_Bridge_Init` と各モーターの `*_Task` が VBUS に合わせて 8 / 9 / 10V に上げます
  (VBUS ≥ 12V で 10V)。子基板 B の TKR74F04PB は 10V 駆動が前提です。
- ゲートを駆動する前に VBUS ≥ 8V を確認してください (サンプルは `Mpb_Vbus_mV() >= 8000` まで待ちます)。

### 止め方 (ブレーキ) の状態 — DC モーター (mpb_dc)

この基板の駆動 (片側 PWM + 反対側ローサイド ON, 同期整流) では, **回生ブレーキと短絡ブレーキは別の状態ではなく duty の連続した点**です
(duty < 逆起電力/VBUS で電流が逆向き = 回生, duty = 0 = 両ローサイド ON = 短絡)。そこで状態は 4 つ + 故障だけにしています。

```
            SetDuty / SetCurrent                    Stop(制動電流)
  COAST ───────────────────────▶ 駆動 (DUTY/CURRENT) ───────────────▶ STOP ──(止まった)──▶ BRAKE(保持) ──(brake_hold_ms)──▶ COAST
 (全 FET OFF) ◀── Coast() ─────────┘   ▲  減速中も VBUS を監視          │ 回生 → (逆起電力/R ≤ 電流上限で) 短絡 
      ▲                                └─────── SetDuty ───────────────┘
      └──── 故障 (過電流・VBUS 上限・ウォッチドッグ): どこからでも全 FET OFF
```

| 状態 | FET | 電力の行き先 | 使いどころ |
|---|---|---|---|
| COAST (惰性) | 全 OFF | なし (逆起電力 > VBUS のときだけダイオード経由で母線へ) | 待機・故障・リセット後 |
| 駆動 | 片側 PWM + 片側ローサイド ON | 母線 → モーター (減速中は逆向き = 回生) | 運転 |
| STOP (停止) | 電流制御 (制動電流一定) | まず回生 (母線へ), 遅くなると短絡 (巻線の熱) | **止めるときはこれ** (`Mpb_Dc_Stop`) |
| BRAKE (保持) | 両ローサイド ON | 巻線の熱 | 止まった後の短時間の保持 (`brake_hold_ms`, その後 COAST) |

- **回生の上限**: USB-PD やベンチ電源は電力を吸い込めない (母線のコンデンサが小さいと 1A の回生で約 10V/ms 上がる)。
  PWM 周期ごとに VBUS を測り, 「平常の VBUS + 1V」(`brake_vbus_max_mV` で変更, バッテリーなら上げる) を超えそうなら回生を弱める。
  回生の強さは 0 からゆっくり上げ (約 0.5 秒), 上限に近づくとすぐ下げる。
- **短絡への近道**: 巻線抵抗 (`r_mohm`) が分かっていれば, 逆起電力 ÷ 巻線抵抗 (= 短絡したときの電流) が電流上限以下になった時点で短絡に移る。
  母線へ電力を返さずに止まる (電源が吸い込めない場合の最速)。
- **duty / 電流モードでの減速も保護**: 急に duty を 0 にしても, 制動電流が上限を超えない duty より下げない。
  VBUS が上限を超えたら duty を逆起電力と釣り合う値より少し上にして, 母線の電力をモーターへ戻す (インバーターの減速ストール防止)。
- **しないこと**: 逆転させて止める (プラギング: 電源と逆起電力の両方で大電流), 高速回転中にいきなり短絡 (逆起電力 ÷ 巻線抵抗の大電流)。
  `Mpb_Dc_Brake()` (即時の短絡) は低速での保持用。
- 最後の守り: VBUS が子基板の上限 + 2V (`MPB_VBUS_TRIP_MV`) を超えると全 FET OFF (PWM 周期ごとの監視)。
- 検証: `tests/test_dc.c` がモーター (巻線・慣性) と母線 (吸い込めない電源 + 100µF + MCU の消費 30mA) のモデルで,
  逆転しない・VBUS が上限 +0.6V 以内・電流が上限以内・最後は全 FET OFF・惰性より十分早く止まる・バッテリーなら回生する, を確かめる。
- 3 相 (mpb_bldc) の `Mpb_Bldc_Brake()` は今のところ即時の短絡ブレーキ (同じ方式への対応は今後)。

### ウォッチドッグと「全 FET OFF」(core/mpb_wdt.c, 常に有効)

| 場面 | 動作 |
|---|---|
| 電源投入・リセット (nRST・WDT・ソフト) | ハード: HO (PB9/11/13/15) はリセット値が Low 出力, LO (PB8/10/12/14) は内蔵プルダウン, 子基板の各 FET に 10k/20k の G-S プルダウン → **全 FET OFF**。さらに `main()` の最初に `Mpb_Gates_Off()` で PB8〜PB15 を能動的に Low |
| `loop()` (RTOS ではタスク) が `MPB_WDT_MS` (既定 200ms) 戻らない | WWDG の早期警告割込み (約 29ms ごと) が検出 → **全ゲート OFF → WWDG リセット** (0.5ms 以内) |
| 割込みごと止まった (割込み禁止の無限ループ, クロック異常) | 早期警告が動けないので WWDG が約 29ms でリセット (この間もデッドタイムは固定済みで上下短絡は起きない) |
| ブリッジの設定が壊れた (デッドタイム・極性・TIM1/TIM2 の重なり・ゲートの GPIO High) | 早期警告割込みで毎回点検 → 全ゲート OFF → リセット |
| 過電流 (CMP2/CMP3)・HardFault・NMI・RTOS のスタックあふれ / assert・書き込み要求のリセット | まず `Mpb_Gates_Off()` |

- `Mpb_Gates_Off()` は TIM1 の MOE を切り, PB8〜PB15 を 1 回の書き込みで「GPIO 出力 Low」にする (上下とも OFF = 惰性。短絡ブレーキにもしない)。
- **上下短絡 (同じレッグの HO と LO が同時 ON) の防止**: 相補 PWM + デッドタイム (下限 `MPB_DEAD_MIN_NS` 300ns, 200ns 未満は
  コンパイルエラー, 切り上げ計算)。TIM1 は LOCK レベル 3 でデッドタイム・極性・出力モードをリセットまで固定。
  TIM2 で HB2 を出すときは TIM1 CH3/CH3N を出さない (同じ PB12/PB13 に重ならない)。ピン切替は割込みを止めて行い, 故障中は PWM に戻さない。
- 直前のリセットの原因は `Mpb_ResetCause()` / `Mpb_ResetCauseText()` (例: `MPB_LOGI("reset: %s", Mpb_ResetCauseText(Mpb_ResetCause()))`)。
- `setup()` は `MPB_WDT_SETUP_MS` (既定 3 秒) まで。`loop()` の外で長く回す処理は `Mpb_Wdt_Feed()` を呼ぶ。
  FreeRTOS ではスケジューラ開始後, 最初の給餌 (loop タスク・アイドル・`Mpb_Core_Service()`) から動く。
- 割込みを止める処理は 29ms 未満に: WS2812 は 600 個まで (`MPB_WS2812_MAX`), WS2812 入力の中継は最大 10ms。
- デバッガで止めるとリセットされる (安全側)。デバッグ中だけ `config.h` で `#define MPB_WDT_MS 0` (VBUS を切って作業)。
- 短絡ブレーキ (`Mpb_Dc_Brake` = 両ローサイド ON) はスケッチが明示的に呼んだときだけ。故障・リセットの経路では使わない。

- `mpb_guard` (examples/protect): NTC の温度, 電流 (PWM 同期), VBUS を 1ms ごとに見て, 異常で警報端子を High にします。
  短絡はコンパレータの割込みから直接 High にするので µs 単位で反応します。`latch = 1` なら原因が消えても解除まで保持します。

## FreeRTOS

Arduino 版は「ツール → RTOS → FreeRTOS」([../arduino/README.md](../arduino/README.md#freertos-ツール--rtos--freertos))。
make 版は `Makefile` に `RTOS := freertos` を書くと WCH SDK 同梱の FreeRTOS (V10.4.6) をリンクします (`src/FreeRTOSConfig.h` が必要)。
`setup()` でタスクを作って `vTaskStartScheduler()` を呼びます (`loop()` は呼ばれない)。RAM が 12KB なので静的確保だけにし,
main のスタックは 768 バイト (割込み用に再利用)。書き込み要求の処理 `Mpb_Core_Service()` はどれかのタスクから呼びます。
`mpb_i2c` はタスク間で排他しないので, 同じバスのデバイス (OLED と HT16K33 など) は 1 つのタスクから使います。

## 未実装 / 今後

- 3 相のセンサレス閉ループ (BEMF ゼロクロス)。コンパレータと仮想中性点の設定 (`Mpb_Bemf_*`) はあるが, 転流制御は未実装。
- DC モーターの回転数の実測は, TACH_IN (エンコーダ / FG) か JP8 = 2-3 の電流リップルを `Mpb_Tach_PeriodUs()` で読む。
- 1-Wire (DS18B20)・DHT11 は未対応 (TinyWetherMemo の host 側にはある)。

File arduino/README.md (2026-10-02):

# Arduino IDE / arduino-cli で使う (Boards Manager)

## 入れ方

1. Arduino IDE 2 の **ファイル → 基本設定 → 追加のボードマネージャの URL** に次を足す
   ```
   https://raw.githubusercontent.com/ghostinkoma/mPBCH32M030DS0/main/package_mpbch32m030_index.json
   ```
2. **ツール → ボード → ボードマネージャ** で `mPBCH32M030DS0` を検索してインストール。
   コンパイラ (xPack riscv-none-elf-gcc 14.3.0-1) も自動で入る (このリポジトリの Releases にミラーしたもの)。
3. **ツール → ボード → mPBCH32M030DS0 (CH32M030)** を選ぶ。

arduino-cli:
```sh
URL=https://raw.githubusercontent.com/ghostinkoma/mPBCH32M030DS0/main/package_mpbch32m030_index.json
arduino-cli core update-index --additional-urls $URL
arduino-cli core install mpbch32m030:ch32m030 --additional-urls $URL
arduino-cli compile -b mpbch32m030:ch32m030:mpb:stage=A MySketch
arduino-cli upload  -b mpbch32m030:ch32m030:mpb -P mpbusb MySketch     # USB-C で書き込み
```

## ツールメニュー

| メニュー | 選択肢 | 意味 |
|---|---|---|
| Power stage | A (12V) / B (24V) / C | 子基板。VBUS の分圧比が変わる (`MPB_POWER_STAGE`) |
| UART boot request | On / Off | On: UART (PC2) からの書き込み要求も受ける。PC2 を WS2812 入力や TM1640 に使うときは Off |
| Upload method | USB-C / UART | USB-C: ブートローダへ USB で。UART: 選んだシリアルポートへ |
| RTOS | None / FreeRTOS | FreeRTOS: `loop()` がタスクになり, `delay()` が `vTaskDelay()` になる (下記) |

## 書き込み

* **USB-C**: ポートを選ばずに **スケッチ → 書き込み装置を使って書き込む** (書き込み装置 = `mPB USB-C bootloader`)。
  シリアルポートを選んであれば普通の「書き込み」でもよい (USB-C のときポートは使わない)。
* 書き込みは `tools/mpb_upload.py` を使う: **Python 3** と `pip install pyusb pyserial` が必要。
  Linux は `tools/99-mpb.rules` を `/etc/udev/rules.d/` へ, Windows は Zadig で 1A86:55E0 に WinUSB。
* ブートローダ (firmware/bootloader) はあらかじめ WCH-LinkE で書いておく (Arduino の「ブートローダを書き込む」は未対応)。

## スケッチの書き方

* `Arduino.h` は最小限: `pinMode / digitalWrite / digitalRead / millis / micros / delay / Serial (送信のみ) / analogRead(ADC チャンネル)`。
  端子名は `PA0`〜`PC7`, `LED_BUILTIN` (= PC4, Low で点灯, ボタンと共用なので `OUTPUT_OPEN_DRAIN` で)。
* 本体の機能は **mpbfun** ライブラリ (= `firmware/lib` と同じコード)。例は **ファイル → スケッチ例 → mpbfun**
  (`firmware/examples` の 11 例 + Blink)。FreeRTOS の例は MpbFreeRTOS の下。どれも待たない書き方なので, モーターなどを使うときは `delay()` ではなく
  `MPB_EVERY_MS()` や `millis()` で間隔を測る。
* スケッチに **config.h タブ** を置くと, ライブラリの設定 (`MPB_LOG_BUF` など) とスケッチの `CFG_*` が全ファイルに効く
  (make 版の `src/config.h` と同じ。子基板と UART 書き込みだけはツールメニューで選ぶ)。

## FreeRTOS (ツール → RTOS → FreeRTOS)

ESP32 の Arduino と同じ形です。`#include` は要りません (Arduino.h がライブラリ **MpbFreeRTOS** を自動で読む)。

```cpp
void worker(void *) { for (;;) { /* … */ delay(10); } }   // delay() = vTaskDelay()

void setup() {
  xTaskCreate(worker, "worker", 160, NULL, 2, NULL);      // スタックは語 (4 バイト) 単位
}                                                          // 戻るとスケジューラ開始
void loop() { /* 優先度 1 のタスクとして動く */ }
```

* カーネル: WCH SDK 同梱の FreeRTOS V10.4.6 (RISC-V ポート, SysTick = ティック 1kHz)。RAM は 12KB しかないので,
  既定は **ヒープ 4KB** (`xTaskCreate` / キュー用) + loop タスク 1KB + 割込みスタック 768B。
* 設定を変える: `config.h` タブに `#define MPB_RTOS_HEAP 3072`, `#define configUSE_TIMERS 1`, `#define MPB_LOOP_STACK 320` など。
  全部自分で決めたいときは `FreeRTOSConfig.h` タブを置く (rtos_motor_display の例: 静的確保だけ・ヒープなし)。
* `setup()` の中で自分で `vTaskStartScheduler()` を呼んでもよい (そのとき `loop()` は呼ばれない)。
* スケジューラ開始前 (`setup()` の中) は割込みが止まっている (FreeRTOS の仕様)。`millis()` / `delay()` は使えるが,
  USB や UART の送信は開始後に動く。
* **使えない物**: `mpb_ws2812` / `mpb_wsrx` (SysTick で時間を測るため)。
* **注意**: mpbfun のライブラリ (I2C, ログ, 表示器, モーター) はタスク間で排他しない。1 つの機能は 1 つのタスクから使う
  (例: I2C の OLED と HT16K33 は同じタスク, `Serial` は 1 つのタスク)。
* スタックあふれ・ヒープ不足は検出して停止する (状態 LED が点灯)。`uxTaskGetStackHighWaterMark()` で余裕を確かめる。
* 例: **ファイル → スケッチ例 → MpbFreeRTOS** → `RtosBlink` (タスク 2 本 + キュー), `rtos_motor_display`
  (ステッピング + OLED / HT16K33 ×4 / TM1640 ×4, make 版と同じコード)。

## パッケージの作り方 (保守者向け)

`arduino/RELEASE` の版 (例 `0.1.0`) を書き換えて main に push する
(または `git tag arduino-v0.1.0` を push / GitHub の Actions → arduino-package → Run workflow で版を入力)。

`.github/workflows/arduino-package.yml` が次を行う:

1. WCH SDK を取得し `arduino/build_package.py` でコア `mpbch32m030-<版>.tar.bz2` を作る (同じ入力なら同じバイト列)
2. xPack riscv-none-elf-gcc (Linux x64/arm64, macOS x64/arm64, Windows x64) を本家の Releases から取り,
   **SHA-256 を xPack の公開値と照合**して, このリポジトリの Release にミラーする
3. 全サンプルを arduino-cli でビルドして確かめる
4. Release を作り, 索引 `package_mpbch32m030_index.json` を main に置く (前の版も索引に残す)

手元で試すとき: `python3 arduino/build_package.py --version 0.1.0 --out dist --stage-only` で展開した形を作り,
`<スケッチブック>/hardware/mpbch32m030/ch32m030/` に置くと IDE から使える
(コンパイラは `--build-property runtime.tools.xpack-riscv-none-elf-gcc.path=<xPack のディレクトリ>` で指定)。

**リポジトリは公開 (public) にしておくこと** — 非公開だと IDE から索引もアーカイブも取得できない。

## 中身とライセンス

* `cores/mpb`: Arduino.h + `firmware/core` (起動・USB 書き込み・PD) + WCH CH32M030 EVT の SDK ソース
  (WCH の条件: WCH のマイコン用に限り使用可)
* `libraries/mpbfun`: `firmware/lib` (LICENSE: 個人利用は表示のうえ自由, 商用は sinhex.k@gmail.com へ連絡, 無保証)
* TM1640 ドライバとフォントは ghostinkoma/TM1640MatrixChain (CC BY-NC-SA 4.0) から移植
* コンパイラ: xPack GNU RISC-V Embedded GCC (GPL ほか各ライセンス, https://xpack-dev-tools.github.io/riscv-none-elf-gcc-xpack/)

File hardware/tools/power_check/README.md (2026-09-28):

# 電流容量・ノイズのチェック

銅箔 (配線・ベタ・ビア, 両面) を 0.05mm 格子の抵抗網にして電流分布を解き, IPC-2221 (外層 1oz, ΔT 20°C) と比べる。

```sh
# 1) 形状の書き出し (KiCad 8 の Python)
python3 extract.py ../../daughter/PWR_A/mPBCH32M030DS0_PWR_A.kicad_pcb VIN,VIN_F,VBUS,SW0,SW1,SW2,SW3,SRC0,SRC1,SRC2,SRC3,GND,ISH,USB_VBUS,USB_VBUS_P A.json
# 2) 解く (numpy / scipy / pyamg / pillow)
python3 solve.py A.json "$(python3 cases.py A)" > res_A.jsonl
# 3) 経路ごとの許容電流
python3 rate.py A
```

- 経路 (cases.py): 電源入力 J3→F1→Q9→各ハイサイド、相出力 FET→J4、ローサイド→シャント→R70→J3、USB-PD J1→F3→Q10。
- コネクタのピンは接触抵抗 10mΩ で外部ノードへつなぐ (ピンごとの電流が出る)。部品のパッドは等電位。
- 許容電流は, パッドの口元 0.5mm を除いた最大電流密度から求めた等価幅で判定する。
- `noise.py`: モジュールの 3.3V 系・アナログ系の配線が, スイッチング系 (SW/VB/HO/LO) と同一層で近接する長さと,
  下に GND の無い長さを出す (`extract_all.py` の出力を使う)。

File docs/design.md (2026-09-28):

# 設計検討書 — mPBCH32M030DS0 (Rev 0.4)

> **Rev 0.4**: MCU 周りを DIP-42 のモジュール (22.86 × 53.34mm, ブレッドボード対応) にまとめ、パワー段子基板
> (A: TPN1R603PL / B: TKR74F04PB 24V / C: MTN2306AN3) のピンソケットへ左右対称に挿す構成にしました。
> LED はすべてモジュール上面、電圧系に依存する部品 (TVS・OVP 分圧・バルク容量・相電圧分圧) は子基板側です。
> 子基板 D (ピン引き出し) は廃止しました。コンデンサは耐圧と容量から現実的なサイズ (1005〜1206) を選び直しています。
> Rev 0.3 からの変更点は下記の各表に (Rev 0.4) と記しています。
> 構成・ピン配置・レイアウト・コンデンサ品番は [stacking.md](stacking.md) を参照してください。

> Rev 0.2 の内蔵機能活用 (USB-PD 給電, CMP3 BEMF, QII1, ISOURCE 診断) は [advanced_features.md](advanced_features.md) にまとめています。

CH32M030C8U7 (QFN48) + TPN1R603PL によるユニバーサル・モータードライバの部品選定と回路設計の根拠。
数値の出典は WCH **CH32M030DS0 V1.2 (データシート)**、**CH32M030RM V1.2 (リファレンスマニュアル)**、
WCH 公式 EVT (`openwch/ch32m030`) と東芝 TPN1R603PL データシートです。

---

## 1. 部品選定の妥当性

### 1.1 MCU: CH32M030C8U7 — 妥当

| 項目 | 仕様 (DS) | 本設計での評価 |
|---|---|---|
| コア | QingKe RISC-V3B 72MHz, Flash 64KB, SRAM 12KB | FOC / マイクロステップに十分。20KB をブートローダに割いてもアプリ 44KB |
| プリドライバ | N+N ハーフブリッジ ×4, ブートストラップダイオード内蔵, **デッドタイム・シュートスルー防止回路内蔵** (DS 図1-4) | 外付けゲートドライバ不要 |
| ドライバ能力 | ソース 55mA typ (35 min) / シンク 120mA typ (80 min) @VDD8=10V, 短絡電流 480mA / 740mA (DS 表3-20) | TPN1R603PL (Qg 41nC) を 20kHz で駆動可能 (§2.2) |
| 電源 | VHV 4.0〜29V (絶対最大 30V), VDD8 4.0〜10.5V (5/8/9/10V 選択), VDD33 3.3V。LDO 負荷上限 VDD8 35mA / VDD33 20mA | 12V 系で外部レギュレータ不要。負荷配分は §2.4 |
| PWM | TIM1: 3 相補 + BKIN, **TIM2: 2 相補** (リマップ2 で PB12〜PB15) | 4 レッグすべて相補 PWM (DS 1.4.20) |
| アナログ | OPA3/OPA4 差動 (ゲイン 4/8/16/55, 出力は ADC IN9/IN10 に内部接続), CMP2/CMP3 → TIM1 ブレーキ, 12bit ADC 20ch | 電流検出・過電流遮断を外付け IC なしで実現 |
| USB | USBFS (PB0/PB1) + USB PD ×2 (CC1R/CC2R は Type-C Rd 5.1kΩ 内蔵) | Type-C の外付け Rd 不要 |
| 保護 | OTP (145℃), PB4 分圧入力による過電圧リセット (1.5V しきい値), POR/PDR | VBUS 18V で MCU リセット (§2.5) |
| パッケージ | **QFN48 5×5mm / 0.35mm ピッチ / 各辺 10-14-10-14 ピン**, 裏面パッド = GND (DS 図4-3) | Rev 0.3 は **2 層・0.127mm ルール** (パッド間 0.15mm, 裏面パッドのサーマルビア 0.2mm 穴) で配線。KiCad 標準 QFN-48 5x5 とは**ピン1の位置が異なり非互換** |

**型番の注意**: DS の「QFN48」は **C8U7 (5×5mm)**。**C8U3 は QFN48X7_A (7×7mm, 0.5mm ピッチ)** で
ピン番号が LQFP48 と同じ別パッケージ。本設計のピン番号はすべて **C8U7** の番号。

### 1.2 MOSFET: TPN1R603PL — 12V 系に妥当 (24V 系には不適 → Rev 0.3 で子基板 B を用意)

子基板 A はこの TPN1R603PL を使います。24V 系は子基板 B (TKR74F04PB 40V)、廉価版は子基板 C (MTN2306AN3) を使います。
比較表は [stacking.md](stacking.md#子基板のバリエーション) にあります。

| 項目 | 値 | 評価 |
|---|---|---|
| VDSS | 30V | 12V 系は十分。24V 系は余裕不足 (回生・リンギング) |
| RDS(on) | 1.2mΩ typ / 1.6mΩ max @10V, 4.5V 駆動も規定 | 10A で導通損失 ≤0.24W。VDD8=5V モードでも使える |
| Qg / QSW / Qgd | 41nC / 11nC / 5.4nC (Qgs1 8.9nC) | Qgd/Qgs1 = 0.61 < 1 → dv/dt 誤点弧に強い |
| パッケージ | TSON Advance 3.3×3.3mm (1-3=S, 4=G, 5-8+裏面=D) | **PowerPAK 1212-8 互換ランド** (`Package_SO:Vishay_PowerPAK_1212-8_Single`) を使用。試作前に東芝推奨ランドと照合 |
| 設計電流 | — | 10A 連続 / 20A ピーク (放熱・銅厚で決まる) |

### 1.3 周辺部品

| 部品 | 選定 | 理由 |
|---|---|---|
| ゲート抵抗 | 47Ω + G-S 20kΩ | WCH 評価ボード準拠。ドライバ短絡電流 (480/740mA) を制限 |
| ブートストラップ | 2.2µF/25V X5R **1608** ×4 (モジュールの MCU 裏) | DS 推奨 1〜10µF。DC バイアス後 ≈1.3µF → Qg 41nC で降下 32mV/周期。子基板 B の大きな Qg にも対応 |
| シャント | 各レッグ 10mΩ 2512, バス 10mΩ 2512 | OPA ゲイン切替で ±2.9A〜±20A。バスは ADC 直読み 10mV/A |
| TVS | SMBJ16A (24V 系は SMBJ24A) | 12V 系: クランプ 26V < FET 30V / VHV 絶対最大 30V → 入力 8〜16V。24V 系は安定化電源が前提 |
| ヒューズ (Rev 0.3) | Littelfuse 0451010.MRL (NANO2 2410, 10A) | ブレードヒューズから小型 SMD へ。ピンヘッダ給電 (約 10A) に合わせた定格 |
| 逆接・逆流保護 (Rev 0.2) | LM74700-Q1 + TPN1R603PL のハイサイド理想ダイオード ×2 (子基板 J3 用 U4/Q9, USB-PD 用 U5/Q10) | J3 と USB-PD を安全に OR 接続できる。FET を共通化し、損失は 15A で約 0.3W |
| VHV 給電 | B5819W ×2 のダイオード OR (VBUS / USB 5V) + 47Ω + 27V ツェナー (Rev 0.3) | USB だけでも MCU が起動し書き込み可能。24V 系のサージで VHV 絶対最大 30V を超えない |
| コネクタ (Rev 0.4) | USB-C 以外はすべて 2.54mm ピンヘッダ。モジュールは 1x21 ×2 (DIP-42, 列間 0.7in)、子基板の電源 J3 は 2x6, 出力 J4 は 2x8 | ブレッドボード対応と左右対称の嵌合。大電流は複数ピン並列 (1 ピン約 2.5〜3A, VIN/GND 各 6 本・各相 4 本) |
| コンデンサ (Rev 0.4) | 4.7µF は 1608 (Samsung CL10A475KO8NNNC), 10µF/25V は 2012, 10µF/50V は 1206, 4.7nF/100V は 1608, バルクは低背電解 (高さ 6.2mm) | 1005 の 4.7µF や 1608 の 50V/10µF は入手性・DC バイアス特性が悪い。品番表は [stacking.md](stacking.md#コンデンサのサイズ-耐圧と容量から現実的なサイズを選定) |
| スイッチ (Rev 0.3) | Omron B3U-1000P (3×2.5mm) | TL3342 (4.5mm) から小型化 |
| 水晶 | 8MHz 3225, CL=20pF, 負荷容量 30pF ×2 | DS 表3-9 (CL 20pF, ESR ≤60Ω)。帰還抵抗は内蔵 |
| USB ESD | USBLC6-2SC6 (基準 +3V3) + SMAJ20A (VBUS) | USBLC6 の VBUS ピンは 5.25V 定格のため +3V3 に接続。PD 給電の VBUS (≤20V) は SMAJ20A で保護 |
| 5V | 78L05 | ホールセンサ用 30mA 程度 |

---

## 2. 回路設計の詳細

### 2.1 PWM とハーフブリッジの割当

| モード | HB0 / HB1 | HB2 / HB3 | 電流 IB (JP5) |
|---|---|---|---|
| 3 相 | TIM1 CH1/CH2 (+HB2 = TIM1 CH3) | HB3 未使用 | 1-2 (HB1 = V 相) |
| DC 1ch | TIM1 CH1/CH1N, CH2/CH2N | — | どちらでも |
| DC 2ch / ステッピング | TIM1 CH1/CH2 (A 側) | **TIM2 リマップ2**: PB13/PB12 = CH1/CH1N, PB15/PB14 = CH2/CH2N (B 側) | 2-3 (HB2) |

- TIM1 はデフォルト配置で HB0〜HB2 に接続。**TIM1 リマップ1** でも CH1〜CH3 は同じピンのまま、BKIN が PA13 (nFAULT) に移る。
- TIM2 は BKIN を持たない → B 側の過電流は CMP3 割込みで TIM2 出力を止める (µs オーダ)。A 側は TIM1 ブレーキでハード遮断。
- ドライバ内蔵のシュートスルー防止があるが、FW でも必ずデッドタイムを設定する。

### 2.2 ゲート駆動の見積り

- 平均ゲート電流: 41nC × 20kHz × 8 石 ≈ 6.6mA (VDD8 から)
- スイッチング時間: ターンオン ≈ QSW / 55mA ≈ 0.2µs, ターンオフ ≈ 11nC / 120mA ≈ 0.09µs (+遅延 ≈ 0.25µs)
- **デッドタイム初期値 0.5µs**、PWM **16〜20kHz** を推奨 (実測で詰める)
- 損失 (12V, 10A, 20kHz): スイッチング ≈ 0.5×12×10×0.29µs×20k ≈ 0.35W + 導通 ≤0.24W → 1 石 0.6W 程度

### 2.3 電流・電圧の計測 (内蔵 ADC)

| 信号 | 経路 | ADC | 分解能 / 範囲 |
|---|---|---|---|
| IA (HB0 レッグ) | 10mΩ → R16/R17/C19 → ISP1/ISN1 → **OPA3** | IN9 (内部) | G16: 10mV/A×16, ±10A |
| IB (HB1 or HB2) | 10mΩ → JP5 → R18/R19/C20 → ISP2/ISN2 → **OPA4** | IN10 (内部) | 同上 |
| IBUS (全電流) | バス 10mΩ → R13/C17 → PB3 (直接) | IN1 | 10mV/A, ≈81mA/LSB |
| VBUS | 110k/10k → PB4 | IN17 | ≈9.7mV/LSB, 〜28.8V (入力上限 VDD33−0.9V) |
| 温度 | NTC 10k ← PA4 ISOURCE1 | IN5 | |
| 相電圧 U/V/W | 20k/3k → JP2〜JP4 → PA5/PA7/PA6 | IN6/IN2/(W は ADC 無し) | センサレスは CMP3 + 内部仮想中性点で検出 (docs/advanced_features.md) |
| USB VBUS | 120k/10k → PA2 | IN15 | PD 契約電圧の確認・抜去検出 |
| 過電流閾値 | 12k/1k → PB2 | IN0 | 254mV = 25.4A (読み戻し可) |

- 3 相: Iu = IA, Iv = IB, Iw = −(Iu+Iv)。IBUS は電力計算・保護用。
- ステッピング / DC 2ch: A 相 = IA, B 相 = IB (JP5=2-3)。中心揃え PWM で下側 ON 期間に標本化する。
- ADC は注入グループを TIM1 (TRGO) で起動し、PWM 中央でサンプリングする。

### 2.4 電源と LDO の負荷配分

| 電源 | 負荷 | 概算 |
|---|---|---|
| VDD8 (上限 35mA) | ゲート電荷 6.6mA + ゲート確認 LED (H/L 各 ≈0.36mA×4) + VDD33 全量 | ≈ 25mA |
| VDD33 (上限 20mA) | MCU 12mA (72MHz, 全周辺) + 3V3 LED 0.9mA + 状態 LED + プルアップ | ≈ 15mA |
| VHV (上限 60mA) | 上記全体 | LDO 損失 ≈0.25W (VHV 15V 時) |

- 3.3V 系の外部供給は J4/J5/J6 の 3V3 ピン経由で**数 mA まで**。それ以上は外部で用意する。
- 5V (78L05) はホールセンサと +5V LED、J6 の 5V ピン用 (合計 ≤ 60mA 目安)。

### 2.5 保護

| 事象 | 対策 |
|---|---|
| 逆接続 / 逆流 | U4+Q9 / U5+Q10 の理想ダイオードが遮断 (J1 と USB-PD の相互逆流も阻止) |
| 過電流 | CMP3 (IBUS vs 25.4A) → TIM1 BKIN、CMP2 (IA) → TIM1 BKIN、TIM2 は CMP3 割込みで停止。F1 15A |
| 過電圧 | PB4 OVP: VBUS 18.0V で MCU リセット (全ゲート OFF)。TVS SMBJ16A |
| 過熱 | NTC (FW) + チップ OTP |
| 外部非常停止 | nFAULT (モジュール J2-20, PA13 = TIM1_BKIN_1)。470Ω + 1nF (C120, 0.47µs) で雑音を除去。CH32M030 の TIM1 には BKIN のデジタルフィルタ (BKF) が無いため、ハードの RC が唯一のフィルタ。誤停止からの自動復帰が必要なら BDTR の AOE を使う |
| 起動時 / ブートローダ中 | HO は Low 出力、LO は内部プルダウン (解除不可) + 外部 20k → 全 FET OFF |

### 2.6 ゲート確認 LED

各ハーフブリッジに 2 個 (H: HOx–SWx 間, L: LOx–GND 間, 1005)。22kΩ 直列で約 0.36mA (VDD8=10V)。
Rev 0.4 では**モジュール上面**に移しました (子基板はヒートシンクとモジュールに隠れて見えないため)。
ゲート抵抗より MCU 側の信号を見るので、外付けのパワー段で使う場合も同じように点灯します。
PWM デューティに比例した明るさで点灯し、上下同時点灯が無いこと (= デッドタイムが効いていること) を目視確認できる。
ハイ側 LED の電流はブートストラップ容量から供給される (ダイオード平均上限 7mA に対し十分小さい)。
量産時は R50〜R57 を未実装にして無効化できる。

---

## 3. 作業途中データ (hardware/wip) のレビュー結果

| # | 内容 | 影響 | 対応 |
|---|---|---|---|
| 1 | U1 シンボルのピン番号が **C8U3 (7×7mm) の番号** (PA10=1, PB7=29, PC2 なし) | フットプリントは C8U7 (5×5mm) 形状のため、このままでは全ピンが食い違う | 新回路図は C8U7 番号で作成 |
| 2 | U1 シンボルの GND が **ピン 0**、フットプリントの裏面パッドは **49** | GND が未接続になる | 新シンボルは 49 |
| 3 | Q1 (TPN1R603PL) のフットプリントが **SON-8 3×2mm** | 実装不可 (実物は 3.3×3.3mm) | PowerPAK 1212-8 互換ランドへ変更 |
| 4 | X1 は Abracon ASCO (電源が必要なアクティブ発振器) | 使う場合は OUT→XI, VDD/OE 配線が必要 | 要望どおり受動水晶 8MHz に変更 (ASCO を使う場合は XI 入力の外部クロックモード) |
| 5 | QFN48 フットプリント (CH32M030DS0_QFN48) | **正しい** (10-14-10-14 配置, EP 3.7mm) | そのまま流用 (`hardware/lib`) |
| 6 | USB-C フットプリント GCT USB4105 | 正しい | そのまま流用 |

---

## 4. 残る確認事項 (試作前)

1. TSON Advance の東芝推奨ランドと PowerPAK 1212-8 ランドの寸法照合 (特にドレインパッド形状)
2. I2C リマップ2 (PA14/PA15) 使用時に OPA3/OPA4 の ADC 内部接続と干渉しないこと
   (RM: PA14/PA15 を外部 ADC 入力にする時のみ QDET_EN=1 が必要 → 通常は干渉しない想定)
3. USB のみ給電 (VHV ≈ 4.5V) 時の USB 動作確認 (DS: VHV<5V で PA0〜PA3 の出力振幅が低下。D+/D- は PB0/PB1 なので影響なし想定)
4. TIM2 リマップ2 で HB2/HB3 を駆動する際、TIM1 CH3/CH3N の出力を無効化すること (同一ピンの競合)
5. RST ピン (PC0) はオプションバイトで有効化が必要 (WCH-LinkUtility)
6. Rev 0.2 で追加した内蔵機能 (CMP3 RMID, LM74700, ISOURCE 診断, PD) の確認事項は [advanced_features.md §6](advanced_features.md#6-要実機確認) を参照
7. (Rev 0.3) 子基板 B の TO-220SM(W) ランド: KiCad TO-263-2 で暫定 → 東芝提供ランドへ差し替え。Qg と VDD8 35mA 予算の確認
8. (Rev 0.3) NANO2 ヒューズ (F1) のランド寸法を Littelfuse 推奨値と照合 (`hardware/lib/mPB.pretty`)
9. (Rev 0.4) 子基板のピンソケット (1x21, 高さ 8.5mm) とモジュールのピンヘッダの品番選定。子基板 TOP 面のモジュール下の部品は高さ 7mm 以下を維持
11. (Rev 0.4) バルク容量を低背品 (A: 100µF ×2, B: 47µF ×3) に変更したため、長いモータ電源線では J3 近くに外付けの電解コンデンサを追加する
10. (Rev 0.3) 製造: 2 層 1.6mm, 最小 0.127mm 線幅/間隙, 0.2mm 穴 (QFN サーマルビア) に対応する基板メーカーを選ぶ

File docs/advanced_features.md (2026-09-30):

# 内蔵機能の活用検討 (Rev 0.1 → Rev 0.2)

Rev 0.1 では CH32M030 の内蔵機能を「電流検出と過電流保護」中心にしか使っていませんでした。
Rev 0.2 では、残っていた次の 3 群について**どう適用できるか**を検討し、効果の大きいものを回路とファームウェアに取り込みました。

1. プログラマブル電流源 / シンク (ISOURCE ×2, ISINK ×2)
2. USB-PD / Type-C の高度な機能
3. OPA ×4 / CMP ×3 / DAC の全組み合わせ

数値の出典は CH32M030DS0 V1.2 (DS) と CH32M030RM V1.2 (RM) です。
**実機では未確認**です。推定を含む項目は【要実機確認】と書いています。

## 0. 結論サマリ

| 機能 | Rev 0.1 | Rev 0.2 | 判断 |
|---|---|---|---|
| ISOURCE1 (PA4) | NTC 駆動 | 同じ (工場校正値で温度換算する FW を追加) | 採用継続 |
| ISOURCE2 (PA5) | 未使用 | **モーター結線の自己診断** (パワー段を通電せずに U-V 間の導通を確認) | 採用 (FW のみ) |
| ISINK1/2 (PA6/PA7) | 未使用 | PD PHY の動作に必要な ISINKEN を有効化。ピンは 3 相センシングに割り当て | 一部採用。本来用途 (DC-DC の微調整) は Rev 0.3 案 |
| USB-PD | Rd 受電 (5V) のみ | **PD シンクで 9/12/15V を交渉し、モーター電源として給電** (理想ダイオード OR, 最大 15V/5A) | 採用 (回路 + FW) |
| CMP3 + 内部仮想中性点 + TIM2 捕捉 | 未使用 | **センサレス BLDC の BEMF ゼロクロスをハードウェアで検出** | 採用 (ピン再配置) |
| TIM2 ホール XOR | EXTI で処理 | **同じ PA5/PA6/PA7 でホールセンサインタフェースを使用** | 採用 |
| CMP2 + DAC | IA の第 2 保護 | **JP7 でバス電流に切り替えてサイクル毎の電流制限** (PD 契約電流やセンサレス時の保護) | 採用 |
| OPA1 + CMP1 (QII1) → TIM3 | 未使用 | **タコ / VR センサ入力、ブラシ DC の電流リップル計数** (エンコーダ無しで回転数・位置を推定) | 採用 (JP8) |
| OPA2 + CMP2 (QII2) | 未使用 | 見送り (CMP2 を保護に使うため。入力 PA13 は nFAULT) | 見送り |
| Q_DET (PA14/PA15 出力) | 未使用 | 見送り (I2C に使用。OPA 出力は ADC に内部接続) | 見送り |

**トレードオフ**: GPIO 引き出しから PC3 と PA6 がなくなりました (PD 給電の許可と W 相センシングに使うため)。
状態 LED は PC4 (USER/BOOT) と共用にしています。
2 線 SWD (PA2 = SWCLK) もやめて、1 線 SDI (PA3) にしました。WCH-LinkE の標準は 1 線です。

---

## 1. プログラマブル電流源 / シンク

### 1.1 仕様 (DS 表3-38, RM 20.3)

| ブロック | ピン | 範囲・分解能 | 想定用途 (WCH) |
|---|---|---|---|
| ISINK1 / ISINK2 | PA6 / PA7 | 0〜250µA, 0.244µA/LSB (10bit), 更新 1MS/s, 整定 3µs, 動作にはピン電圧 0.6V 以上が必要 | 外付け DC-DC の FB に電流を注入し、出力を 20mV 刻みで調整する (PPS) |
| ISOURCE1 / ISOURCE2 | PA4 / PA5 | 2 ギア (High/Low)。電流値は工場校正値 (`ISOURCEx_GetData()`, nA) | NTC による温度測定 |

どちらも `PWR_ISINKCmd(ENABLE)` (ISINKEN) が前提です。また USB PD PHY を使う場合も ISINKEN が必要です (RM 15.2 注記)。

### 1.2 適用結果

- **ISOURCE1 → NTC (継続)**: 抵抗は R = V / I (I は工場校正値) で求め、B 定数の式で温度に換算します (`Mpb_Ntc_DeciCelsius()`)。
  外付けの分圧抵抗が不要になり、R110 は DNP のまま使いません。
- **ISOURCE2 → モーター結線の自己診断 (新規)**
  - PA5 は SENS_U (BEMF_U の分圧点) につながっています。ここへ Is を注入すると、モーターが接続されていれば
    `BEMF_U → 20k → OUT0 → 巻線 → OUT1 → 20k → BEMF_V → 3k → GND` の経路ができます。
  - その結果、PA7 (ADC) に **BEMF_V ≈ Is × 131Ω** が現れます (Is = 100µA なら約 13mV = 16LSB)。
  - 未接続・断線なら 0V です。**FET を一度も ON にせずに**、「モーター未接続」「U/V 断線」を起動前に検出できます。
  - 条件: JP2/JP3 = 1-2、ゲート OFF (`Mpb_SelfTest_Wiring()`)。W 相 (PA6) には ADC がないため、W の断線は低電力の試験パルスで確認します (FW)。
- **ISINK1/ISINK2**
  - ピンが CMP3 の N 入力 (PA6/PA7) と同じです。Rev 0.2 では 3 相センシングを優先したので、ISINK 出力は使いません。
    ただし PD のために ISINKEN は常時有効です。
  - ISINK の本領は「ソフトウェアで出力電圧を 20mV 刻みで変えられる DC-DC」です。モーター基板では、**可変補助電源 (AUX 3.3〜12V)** として活きます
    (ファン・サーボ・センサ・LED テープへの給電)。
    FB 分圧の上側抵抗を R1 とすると、Vout = VFB·(1 + R1/R2) + I_SINK·R1 です。R1 = 80kΩ なら 0.244µA × 80k ≈ 19.5mV/LSB、
    全範囲で 20V です。
  - → **Rev 0.3 案**: ステッピング / DC モードでは PA6/PA7 が空くので、ジャンパで ISINK2 を AUX 降圧の FB に接続できます
    (3 相モードでは既定電圧で固定)。

---

## 2. USB-PD / Type-C

### 2.1 Rev 0.1 の状態

CC1R/CC2R 内蔵の Rd で 5V を受電し、USB FS (書き込み) と MCU への給電だけに使っていました。PD 通信はしていませんでした。

### 2.2 Rev 0.2: PD シンクでモーター電源を得る

```
USB-C VBUS ─F3 5A─ USB_VBUS_P ─┬─ Q10 (TPN1R603PL) ── VBUS (モーター電源)
                               │   └ U5 LM74700 (理想ダイオード, EN = PC3)
                               ├─ D9 SMAJ20A (子基板 B のみ)
                               └─ 120k/10k → PA2 (USB_VBUS_SNS, ADC IN15)
J1 12V ─F1 15A─ VIN_F ── Q9 (TPN1R603PL) ── VBUS
                          └ U4 LM74700 (理想ダイオード, 常時 ON = 逆接保護を兼ねる)
```

| 項目 | 設計 |
|---|---|
| 交渉 | PD0 (CC1/CC2 = PA0/PA1)。WCH `USBPD_SNK` を移植 (`pd_process.c`)。Source_Capabilities の固定 PDO から **8〜15V で最も高い電圧** (同電圧なら電流の大きい方) を要求 (`Mpb_PD_SelectPdo()`) |
| 15V 上限の理由 | VBUS 側の TVS SMBJ16A (Vwm 16V)、MOSFET 30V、VHV 絶対最大 30V。20V PDO は要求しない |
| 給電許可 | PS_RDY を受信し、USB VBUS が契約電圧の ±10% に入っていることを PA2 で確認してから PD_PWR_EN = High |
| 遮断 | USB VBUS < 3.5V (抜去) か契約電圧から逸脱したら即 OFF。MCU リセット中は R6 で OFF。**PB4 の OVP リセット (VBUS 18V) でも自動で OFF** |
| J1 との共存 | **理想ダイオード OR**。電圧の高い側が供給し、互いに逆流しない (J1 12V と PD 15V を同時につないでも安全)。PD ソースが電流制限で落ちると、自動的に J1 へ引き継がれる |
| 逆接保護 | Rev 0.1 の GND 側 FET (Q9) は、U4 + Q9 のハイサイド理想ダイオードに置き換え (−65V まで耐える) |
| ESD | USBLC6-2SC6 の VBUS ピン定格は 5.25V → 基準を +3V3 に変更。VBUS には SMAJ20A |
| 電流 | ケーブル 3A (e-marker 付きで 5A)。15V × 3A = 45W、15V × 5A = 75W。FW で IBUS を契約電流以下に制限し、CMP2 + DAC でサイクル毎の上限も設定可能 |

### 2.3 見送った / 将来の PD 機能

| 機能 | 判断 |
|---|---|
| PPS (プログラマブル電源) | WCH サンプルは PPS APDO を除外する。電圧を細かく選べる利点はあるが、モーター用途では固定 PDO で十分 → 将来 |
| PD1 (CC3/CC4 = PA2/PA3) でのソース / DRP | PA2 を USB VBUS 監視、PA3 を SDI に使うため見送り。2 ポート目の USB-C で外部機器へ給電するなら Rev 0.3 で検討 |
| BC1.2 / DCP 判定 | 5V (最大 1.5A) しか得られずモーター駆動には不足 → 使わない |
| USB FS とデータの同時利用 | 対応済み。PD シンク中も USB ベンダーインターフェース (書き込み・設定) は使える |

---

## 3. OPA / CMP / DAC の組み合わせ

### 3.1 ブロックと接続可能性 (RM 第 17 章)

| ブロック | 入力 | 出力先 | 主な設定 |
|---|---|---|---|
| OPA1 (QII1) | PA12 (90kΩ 入力, 自己バイアス 1.23V) | CMP1, ADC IN19 | AV 20/40 |
| OPA2 (QII2) | PA13 | CMP2, ADC IN18 | AV 5/10/20/40, QII / 増幅モード |
| OPA3 (ISP1) | ISP1 / PA8 (ISN1) or VSS | ADC IN9, CMP2 P, CMP3 P | 4/8/16/55, バイアス 0.55/1.6V |
| OPA4 (ISP2) | PA10 / PA11 or VSS | ADC IN10, CMP3 P | 同上 |
| CMP1 | OPA1 出力 | **TIM3 CH1 捕捉**, PA12 | ヒス 100/200mV, デジタルフィルタ |
| CMP2 | P: PB5 / OPA2 / OPA3、N: PB6 / VB / **DAC (0.1〜3.1V, 0.2V 刻み)** / VSS | **TIM1 BKIN**, 割込み, PA13 | ヒス 0〜200mV, フィルタ 375ns〜12µs |
| CMP3 | P: PA3 / PB0 / PB1 / PB3 / OPA3 / OPA4、N: PA5 / PA6 / PA7 / PB2 / DAC、**内部仮想中性点 RMID (80kΩ ×3)** | **TIM1 BKIN**, **TIM2 CH1〜4 巡回捕捉** (TIM1 CC4/CC5・TIM2/TIM3 CCx で切替), PB4/PB5 | ヒス 0〜40mV, フィルタ |

### 3.2 Rev 0.2 の割り当て (モード別)

| モード | JP7 / JP5 | OPA3 | OPA4 | CMP2 | CMP3 | OPA1+CMP1 | TIM2 |
|---|---|---|---|---|---|---|---|
| 3 相 FOC (2 シャント) | 1-2 / 1-2 | IA = U 相 (差動) | IB = V 相 | IA 過電流 (DAC) | **バス過電流** (PB3 vs PB2) | タコ等 | (空き) |
| 3 相 ホール 6 ステップ | 1-2 / 1-2 | IA | IB | IA | バス過電流 | — | **ホール XOR** |
| 3 相 センサレス 6 ステップ | **2-3** / 1-2 | **バス電流 (単端)** | IB | **バス過電流 (DAC)** | **BEMF: 各相 (N) vs 仮想中性点 → TIM2 捕捉** | — | BEMF 捕捉 |
| DC ×2 / ステッピング | 1-2 / 2-3 | A 相 | B 相 | A 相電流制限 | バス過電流 | — | HB2/HB3 PWM |
| ブラシ DC + リップル計数 | 1-2 / — | 電流 | — | 電流制限 | バス過電流 | **JP8=2-3: 整流子リップル → TIM3** | — |

ポイント:
- **3 相センシングを PA5/PA6/PA7 に集約**しました (Rev 0.1 の W 相 = PA12 を PA6 へ移動)。これで次の 3 つが同じ 3 本のピンで使えます。
  - CMP3 の N 入力 (N0/N1/N2) と内部仮想中性点 (RMID)
  - TIM2 CH1/CH2/CH3 (ホール XOR)
  - ISOURCE2 / ISINK1 / ISINK2
- センサレス時の比較タイミングは TIM1 CC4 (PWM ON の中央) で CMP3 を切り替えます。スイッチングノイズを避け、結果は TIM2 の CH1→CH2→CH3 に巡回で捕捉されます。
  ソフトウェアの仕事は、転流ごとに浮き相 (NSEL) を選ぶことだけです (`Mpb_Bemf_SelectPhase()`)。
- CMP3 を BEMF に使う間は、**JP7 でバス電流を OPA3 に通し、CMP2 + DAC で保護**します。どのモードでもハードウェアの過電流遮断が残ります。
- DAC (4bit) は粗いですが、OPA3 のゲインで分解能を作れます。G = 16 なら 1 ステップ (0.2V) = 1.25A、G = 8 なら 2.5A (`Mpb_Ocp_DacCode()`)。
- QII1 は本来、ワイヤレス充電の Q 値検出用の AC 小信号アンプ + コンパレータです。AC 結合 (C105) 入力と TIM3 捕捉を活かして、次に使います。
  - **周期計測**: ファン FG、VR センサ、光学センサなどの小振幅パルス
  - **ブラシ DC の整流子リップル計数**: バス電流の AC 成分。エンコーダ無しで回転数・位置を推定できる
  - ゲイン 40 × リップル数 mV が CMP1 のヒステリシス (100mV) を超えない小型モーターでは、OPA1 出力を ADC IN19 で取り込み、ソフトウェアで検出する
- 見送り: OPA2/QII2 (CMP2 を保護に使うため)、Q_DET 出力ピン (PA14/PA15 を I2C に使うため)、CMP3 のアナログ / プッシュプル出力 (PB4/PB5 は VBUS 監視・水晶)。

---

## 4. 回路変更の一覧 (Rev 0.1 → 0.2)

| ピン / 部品 | Rev 0.1 | Rev 0.2 |
|---|---|---|
| PA2 | SWCLK (2 線デバッグ) | **USB VBUS 監視 (ADC IN15)**, R7/R8/C7 |
| PA6 | 状態 LED / GPIO | **SENS_W** (CMP3 N1, TIM2 CH2, ISINK1) |
| PA12 | SENS_W | **QII_IN** (OPA1 → CMP1 → TIM3) |
| PC3 | GPIO (J6) | **PD_PWR_EN** (U5 EN, R6 プルダウン) |
| PC4 | USER/BOOT | USER/BOOT **+ 状態 LED** (+3V3–LED–1k–PC4, オープンドレイン Low 点灯) |
| J1 入力 | Q9 (GND 側逆接保護) + R1/R2/DZ1 | **U4 LM74700 + Q9 (ハイサイド理想ダイオード)** |
| USB 給電 | PTC 0.5A → VHV のみ | + **F3 5A → U5 LM74700 + Q10 → VBUS**, D9 SMAJ20A (B のみ。A/C は Q10 経由で VBUS 側の TVS D1 が受ける) |
| U3 USBLC6 | VBUS ピン = USB VBUS | VBUS ピン = **+3V3** (PD 20V 対策) |
| JP7 (新) | — | OPA3 入力 = HB0 レッグ / バス |
| JP8 + R123 + C105 (新) | — | QII1 入力 = TACH_IN (J6-5) / バス電流リップル |
| J6 | GND/3V3/PC3/PC4/PA6/PC5/nFAULT/5V | GND/3V3/PC4/PC5/**TACH_IN**/nFAULT/5V/GND |
| J7 | 5P (SWDIO/SWCLK/RST) | **4P 1 線 SDI** (3V3/SWIO/RST/GND) |

## 5. ファームウェア (`firmware/core/mpb*.c`, 応用は `firmware/lib/` と [firmware/README.md](../firmware/README.md))

| API | 内容 |
|---|---|
| `Mpb_Time_Init/Micros/Millis` | TIM3 1MHz 時間基準 (TIM3 CH1 はタコ捕捉と共用) |
| `Mpb_ISense_Init/mA` | OPA3/OPA4 (ゲイン, バイアス 1.6V, JP7 に合わせ差動 / 単端) |
| `Mpb_Ocp_BusCmp3_Init` / `Mpb_Ocp_Cmp2_Init` / `Mpb_Ocp_DacCode` | ハード過電流遮断 (TIM1 BKIN) + 割込みで TIM2 側も停止 (`OPA_IRQHandler`) |
| `Mpb_Bemf_Init/SelectPhase` | CMP3 + RMID + TIM1 CC4 同期 + TIM2 巡回捕捉【要実機確認】 |
| `Mpb_Hall_Init` | TIM2 ホールセンサ XOR |
| `Mpb_Tach_Init/PeriodUs` | QII1 (OPA1+CMP1) → TIM3 CH1 |
| `Mpb_Ntc_Init/DeciCelsius` | ISOURCE1 + 工場校正値 + B 定数 |
| `Mpb_SelfTest_Wiring` | ISOURCE2 による結線診断 |
| `Mpb_PD_Init/Task/Status` | PD シンク交渉 + 給電パス制御 (ポリシー: 8〜15V) |

`sketch.c` は PD 交渉・温度・過電流保護を初期化し、PD 給電中は LED を速く点滅させる例です。
ビルドは GCC 13 で警告 0 (アプリ 10.5KB / 44KB)。

## 6. 【要実機確認】

1. **CMP3 の RMID**: 仮想中性点が P 側に入るという解釈 (PSEL = 0x7 = 未接続、リセット値) は RM 図 17-4 からの推定。チャネル切替と TIM2 巡回捕捉の対応も含めてオシロで確認する
2. **LM74700-Q1 のピン配置** (KiCad 公式シンボル: 1 VCAP, 2 GND, 3 EN, 4 CATHODE, 5 GATE, 6 ANODE) と EN しきい値 (3.3V ロジックで ON できること)、VCAP コンデンサの接続先
3. ISOURCE1/2 の実電流 (工場校正値) と、結線診断の判定しきい値 (理論値の 30%)
4. PD の相互接続性 (WCH サンプル自体に「互換性の問題があり得る」との注記がある)。複数の充電器で 9/15V の交渉と抜去検出を確認する
5. USB-C コネクタ (GCT USB4105) とケーブルの定格電流、F3 の溶断特性、VBUS 充電時の突入電流 (PD ソースの OCP が働かないこと)
6. QII1 のリップル計数に必要な信号振幅 (モーターごとにゲイン・ヒステリシスを調整)

## 7. Rev 0.3 の候補

- ISINK2 で出力を調整できる**可変 AUX 降圧電源** (3.3〜12V / 1A, ステッピング・DC モード時)
- PD1 (CC3/CC4) で 2 ポート目の USB-C (ソース / DRP) を設け、外部機器へ給電する
- PPS 対応 (PD 電圧を 20mV 刻みで最適化し、モーターの効率点に合わせる)

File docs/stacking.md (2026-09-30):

# MCU モジュール + パワー段子基板 (Rev 0.4) — 構成と基板レイアウト

Rev 0.4 では、MCU 周りを **DIP-42 のモジュール** (ブレッドボードに挿せる幅) にまとめました。
MOSFET 群 (パワー段) は子基板 A / B / C に分け、モジュールを子基板のピンソケットへ上から挿して使います。

```
                ┌──────────── MCU モジュール TOP 面 (上向き) ────────────┐
                │ USB-C / RESET・USER / JP2-4・JP8 / LED (電源・状態・ゲート ×8) │
                └──────────── MCU モジュール BOTTOM 面 ──────────────────┘
                   J1 (1x21)  ↓   小型 CR (高さ ≤1.65mm)   ↓  J2 (1x21)      ← ピンヘッダ (標準 2.54mm)
                   J1 (1x21)  ↑  バルク容量・電源部品 (≤7mm) ↑  J2 (1x21)     ← ピンソケット (高さ 8.5mm)
                ┌──────────── 子基板 TOP 面 ────────────────────────────┐
                │  ソケット ×2, 電源入力 J3 (2x6), モータ出力 J4 (2x8), 電源部       │
                └──────────── 子基板 BOTTOM 面 (ヒートシンク側) ───────────────┘
                     MOSFET ×8 / シャント / ゲート抵抗 / 電流チャネル選択 JP5・JP7
```

- **嵌合は左右対称**です。モジュールの左右端にある 1x21 ピン 2 列 (列間 17.78mm) を、子基板の同じ位置の 1x21 ソケット 2 列で受けます。
  Rev 0.3 は基板間コネクタが片側に寄っていたため、モジュールが傾いて接触不良の原因になりました。Rev 0.4 では 42 本のピンが
  基板の全長にわたって均等に荷重を受けます。
- モジュール J1/J2 と子基板 J1/J2 は**同じピン番号・同じネット名**です (鏡像になりません)。回路図生成スクリプトの同じピン表
  (`EDGE_L` / `EDGE_R`) から両方を作っています。並び順は CH32M030 (QFN48) の各辺のピン順に合わせ、
  モジュール上の引き出し配線が交差しにくいようにしています (上辺 → J1/J2 上部、ゲート → J2 中央、アナログ → J1 下部)。ピン配置は [README](../README.md#モジュールのピン配置-上面から見て-usb-c-が上-子基板のソケット-j1j2-も同じ) を参照してください。
- 基板の間隔は約 11mm です (ソケット 8.5mm + ピンヘッダのプラスチック 2.5mm)。子基板 TOP 面のモジュール真下には
  **高さ 7mm 以下**の部品 (バルク容量 EEE-FK 6.2mm など) を置いています。
- **LED はすべてモジュール上面**です。子基板の BOTTOM 面はヒートシンクで覆われ、TOP 面はモジュールの下に隠れるためです。
  ゲート確認 LED (D10〜D17) は HOx–SWx / LOx–GND の間に 22kΩ 経由で接続しています。ゲート信号はモジュール上にあるので、
  子基板を付けずに外付けのパワー段で使う場合も点灯します。
- 電圧系に依存する部品 (TVS D1、VBUS 分圧 R11/R12 = OVP、バルク容量、相電圧分圧) は子基板側にあります。
  モジュールはどの子基板でも共通です。

## ブレッドボードで使う

- モジュールは 22.86mm 幅 (**9 マス**) × 53.34mm (21 マス)、端子列は 0.7in 間隔 (Raspberry Pi Pico と同じ) です。
  一般的な 82 × 52mm (30 列) のブレッドボードに、中央の溝をまたいで左右対称に挿せます (端子は c 列と h 列)。
  両側に 1 列ずつ (a / j) 配線用の穴が残ります (b / i 列は基板の縁の真下)。
- ピンヘッダは **BOTTOM 面に実装し, ピンを下 (MCU と反対側) へ出します** (樹脂部は BOTTOM 面側)。
  - ブレッドボードや子基板のソケットに挿しても, USB-C・RESET / USER・BOOT ボタン・LED は上を向いたままです。
  - ピンを MCU と同じ側 (上) へ出すと, ブレッドボードに挿したときに USB-C が当たり, ボタンも押せなくなるので不可です。
  - ピン番号 (1〜21) は TOP 面 (MCU 側) の各ピンの外側に印字しています。
  - 信号名は BOTTOM 面のシルクに、各ピンの内側 (樹脂部の横) に印字しています (TOP 面は部品で埋まっているため)。
- USB-C だけで MCU・書き込み・USB 通信が動作します。モータを回すには VBUS ピンに 8V 以上を入れ、
  HO/LO/SW に外付けのパワー段をつなぎます。VBUS_SNS には外付けの分圧 (110k/10k など) が必要です。

## 子基板のバリエーション

| | **A** (標準) | **B** (24V 系) | **C** (廉価版) |
|---|---|---|---|
| MOSFET | TPN1R603PL ×8 (30V 1.6mΩ, TSON Advance) | **TKR74F04PB ×8** (40V 0.74mΩ, TO-220SM(W)) | **MTN2306AN3 ×8** (30V 5.5A 25mΩ, SOT-23) |
| モータ電源 VBUS | 8〜16V (公称 12V) | 12〜24V (上限 26V, 安定化電源) | 8〜16V |
| 連続電流の目安 (1 相) | 約 4A (1oz のまま) / **約 5A** (電源ベタにはんだ盛り 0.3mm) | 約 5A (1oz のまま) / **約 7A** (はんだ盛り 0.3mm) | 約 3A (MOSFET 律速) |
| 基板寸法 | **22.86 × 74.9mm** | **44.6 × 99.5mm** | **22.86 × 74.9mm** |
| ゲート抵抗 / G-S | 47Ω / 20kΩ | 22Ω / 10kΩ | 47Ω / 20kΩ |
| シャント (各レッグ + バス) | 10mΩ 2512 2W | 10mΩ 2512 3W | 10mΩ 1206 0.5W |
| バルク容量 | 150µF/25V ×1 (Panasonic EEE-FK1E151P, 8 × 6.2mm, − 側は ISH) | 47µF/35V ×3 (EEE-FK1V470P, 6.3 × 6.1mm) | 100µF/25V ×1 (− 側は ISH) |
| TVS / OVP 分圧 | SMBJ16A / 110k:10k (18V) | SMBJ24A / 180k:10k (28.5V) | SMBJ16A / 110k:10k |
| 相電圧分圧 (BEMF) | 20k / 3k | 47k / 3.3k | 20k / 3k |
| ファームウェア | `make POWER_STAGE=A` (既定) | `make POWER_STAGE=B` | `make POWER_STAGE=C` |

- バルク容量は Rev 0.3 の 470µF/330µF (背が高い) から、モジュール下に収まる**高さ 6.2mm の低背品**に変えました。
  容量が減った分、モータ電源の配線は短くし、必要なら J3 の近くに外付けの電解コンデンサを追加してください。
- **B** の注意点 (24V 系):
  - CH32M030 の VS 絶対最大は 30V、VHV の動作範囲は 5〜28V です (データシート表 3-1)。
    24V 系は安定化電源専用とし、回生やサージで 28V を超えないようにしてください。
    モジュールの VHV は R10 47Ω + D4 27V で保護しています。
  - TKR74F04PB はゲート電荷が大きいので、VDD8 LDO (35mA) の予算を確認してください。
    `8 × Qg × fPWM + MCU の消費 ≤ 35mA` が条件です (例: Qg 150nC なら fPWM ≤ 20kHz)。
  - TO-220SM(W) のランドは、KiCad 標準の TO-263-2 で暫定的に作っています。
    東芝提供のランドパターンに差し替えてから発注してください。
- **C** は SOT-23 の小型品です。小型 DC モータやステッピング (≤1.5A/相) 向けです。

## 基板レイアウト (2 層)

生成手順 (`hardware/gen_pcb.py`, KiCad 8.0 の pcbnew):

1. 部品を配置します (courtyard の重なり・反対面の THT 穴との干渉を検査)。
2. Freerouting 1.9 で自動配線します。
3. 大電流ネットの周囲をベタで太らせます。
4. GND ベタ (両面) とスティッチングビアを入れます。
5. 自動配線で残った接続を格子 A* で補修します。DRC が増えない経路だけを採用します。
6. DRC を実行します。

図は `docs/pcb/*_top.svg` / `*_bottom.svg` です (BOTTOM 面は裏から見た鏡像)。

### MCU モジュール (22.86 × 53.34mm)

| 面 | 上から順に |
|---|---|
| **TOP** | USB-C J8 → ESD U3・RESET SW1 → CH32M030 (QFN48, 中央) → ゲート LED ×8 → センシング選択 JP2〜JP4・JP8、VHV 保護 D4〜D6・F2 → USER/BOOT SW2 → 電源 LED ×3・状態 LED |
| **BOTTOM** | USB 周りの CR → MCU のデカップリング (QFN の裏面パッドのサーマルビアを避けて上側) → 水晶 Y1・C131/C132 (XI/XO 直下) → ブートストラップ C21〜C24 (ゲートピン側)・電流アンプ入力 RC → ホール入力 RC・I/O 直列抵抗 |

- QFN (0.35mm ピッチ) の引き出しのため、線幅・間隙は 0.127mm です (JLCPCB の 2 層標準の最小値)。
- BOTTOM 面の部品はすべて 1.65mm 以下 (最も高いのは 1206 の 10µF。3D モデルで確認) で、ピンヘッダのプラスチック (2.5mm) より低いので、ブレッドボードにもソケットにも当たりません。

### 子基板 A / C (22.86 × 74.9mm)

大電流の銅箔 (VBUS・各相 SW・SRC・ISH・VIN・GND) は**配線より先に固定のベタとして置き**, 残りの信号だけを自動配線しています
(`gen_pcb.py build_daughter_a`)。上から順に:

- 上端 (モジュールの USB 側): USB-PD 経路 F3 → Q10 (理想ダイオード U5) → VBUS, 78L05 U2, バルク容量 C7 (TOP)。
- レッグ 3 → 0 (J2 の HO/SW/LO の並びと同じ高さ)。BOTTOM 面にハイサイド/ローサイド MOSFET・シャント・レッグの C,
  TOP 面に各相の SW 帯 (J4 へ下る縦の帯) と VBUS 帯。ゲート抵抗 (A は 0805) は J2 の HO/SW/LO の間に置いています。
- レッグ 0 の下: バスシャント R70・相電圧分圧・VBUS 分圧 (BOTTOM), NTC TH1 (TOP), 電源入力 Q9 (理想ダイオード U4)・F1。
- 下端: **J3 (電源, 左) と J4 (モータ出力, 右) は縦向き**です。J3 は上 3 段が GND・下 3 段が VIN、J4 は**上から OUT3 → OUT0** の順です。
- 電流チャネル選択 JP5 / JP7 は TOP 面の J1 の横です (はんだジャンパ, 既定は 1-2 ブリッジ)。
- ヒートシンクは BOTTOM 面の MOSFET に絶縁シートを挟んで当ててください (ドレインは VBUS / 各相出力です)。
- USB 側の TVS (旧 D9) は置き場所が取れず外しました。USB_VBUS のサージは Q10 のボディダイオードを通って VBUS のバルク容量と
  TVS D1 で吸収され、LM74700 (U5) の耐圧は 65V です。

#### 電源ベタのはんだ盛り (1oz のまま電流を増やす)

電源ベタの上はレジストを開けてあり (ベタの形を 0.25mm 内側に縮めた開口), はんだを盛って厚みを稼げます。
銅の縁と隣のネットの間はレジストが残るので, 盛ってもブリッジしにくくなっています。

- はんだ 0.3mm (Sn63Pb37) で, 1oz の銅にほぼ 1oz を足したのと同じ効果です (はんだの抵抗率は銅の約 8.5 倍)。
  電流容量チェック (`hardware/tools/power_check`, 1mm 平均の電流密度, IPC-2221 外層 ΔT 20°C) の結果:

  | | 1oz のまま | はんだ 0.3mm |
  |---|---|---|
  | A (設計 5A/相, USB 3A) | 最小 4.1A (SW2) / USB 経路 5.1A | **最小 5.9A** (SW) / USB 経路 5.1A |
  | C (設計 3A/相, USB 3A) | 最小 4.1A / USB 帰路 GND 3.0A | 最小 5.9A / USB 帰路 GND 3.0A |

- **表面処理のハンダレベラー (HASL) だけでは厚みはほとんど増えません** (数〜数十 µm)。効果を出すには, 基板が届いてから
  開口部にはんだを手で盛ってください (はんだごて + 太めの糸はんだ, または開口部にペーストを塗ってリフロー)。
  A の最小経路 (SW) の許容電流: 盛り無し 4.1A / HASL 相当 0.02mm 4.2A / 0.1mm 4.7A / 0.2mm 5.3A / 0.3mm 5.9A。
- BOTTOM 面 (ヒートシンク側) の盛りは 0.3〜0.5mm 以下にしてください (MOSFET の高さ + 放熱シートより低く)。
- 盛ったはんだは**低温はんだ (Sn-Bi など) 不可**です (融点・強度とも不足)。手直しで部品を外すときは, 盛ったはんだも溶かす必要があります。

### 子基板 B (44.6 × 99.5mm, 丸端子・ヒートシンク直付け)

24V 系で電流を取るため, 基板を縦長にして**電源と 4 相の出力を M3 の丸端子 (圧着端子) で直接受ける**構成にしました。
部品は A/C と同じ考え方で, 大電流の銅箔を配線より先に固定のベタとして置き, 電源ベタはレジストを開けてはんだを盛れます。

```
   ヒートシンク                                  ← M3 ネジ ×2 (H1/H2) で子基板へ固定
   放熱パッド (テープ, 絶縁)                      ← TO-263 のタブ (VBUS / SW) の上に貼る
   MOSFET ×8・シャント (BOTTOM 面)
 ═══════════ 子基板 B ═══════════
   丸端子台 ×6 (J3 VIN / J5 GND / J40〜J43 OUT0〜3)・ピンソケット J1/J2 (TOP 面)
   MCU モジュール (ソケットに挿す)
```

- **組み付けの向き**: 実機では BOTTOM 面 (MOSFET) が上, ヒートシンクがいちばん上に来ます。端子台・モジュールは下向きです。
  端子台・ソケットのリードは BOTTOM 面へ 1〜2mm 出ますが, ヒートシンクは TO-263 (高さ約 4.5mm) + 放熱パッドの上に載るので当たりません。
- **端子台**: Würth REDCUBE THR WP-THRBU 74650073 (M3 雌ネジ, リフロー対応の挿入端子) ×6。
  - 上端: 左 J5 **GND**, 右 J3 **VIN** (VIN → F1 → 理想ダイオード Q9 → VBUS)。
  - 下端: 左から J40〜J43 = **OUT0〜OUT3** (各レッグの SW, MOSFET の真下から最短)。
  - 丸端子は TOP 面 (モジュール側) から M3 ネジで締めます。**ネジは端子台を突き抜けない長さ**にしてください
    (貫通すると BOTTOM 面側の放熱パッド・ヒートシンクに当たります)。
- **ヒートシンク固定穴** H1 / H2: M3 (φ3.2mm 非めっき), 基板の中ほど (y = 43mm, x = 4.0 / 36.6mm)。
  ネジ頭と座金は TOP 面側, ヒートシンク側はタップかナットで受けてください。
- BOTTOM 面: 4 レッグを横に並べ, 各レッグは上からシャント → ローサイド → ハイサイドの順 (TO-263 のリードは上向き)。
  ハイサイドのタブは裏面の 1 本の VBUS 帯に, ローサイドのタブ (SW) はビアの列で TOP 面の SW 帯 → 出力端子へつなぎます。
- TOP 面: モジュール真下に USB-PD 経路・78L05・バルク容量 C7〜C9, 右端に VIN → F1 → Q9 → VBUS 帯 (表裏の 2 層で下る),
  中段にゲート抵抗 (BOTTOM, J2 の並び順) と相電圧分圧, 左端に GND 帯 (J5 → バスシャント R70 → ISH)。
- TVS D1 と C1 の − 側は ISH (バスシャントの手前) です。モータ電流が R70 を通らずに帰らないようにしています。
- 電流容量 (電流容量チェック `hardware/tools/power_check`, IPC-2221 外層 ΔT 20°C, 1 相あたり):

  | | 1oz のまま | はんだ 0.3mm |
  |---|---|---|
  | 最も細い経路 (VBUS: Q9 → レッグ 3 の横 / ISH: R34 → R70) | 5.4A | 7.4A |
  | 相出力 (SW, FET → 出力端子) | 8.4A | 12.7A |
  | 電源入力 (J3 → F1) | 10.7A | 17.4A |

  端子台自体 (定格 50A 以上) と MOSFET (0.74mΩ) には余裕があり, 銅箔が律速です。
  10A/相 は 2 層 1oz では届かないため目標から外しました (はんだ盛りで約 7A まで)。
  USB-PD からの給電経路 (Q10 → VBUS, モジュール真下を裏面 1.2mm 幅で下る) は約 3.4A なので, **B で USB-PD 給電するのは 3A まで**にしてください
  (B は 24V 系で, USB-PD の 9〜15V は補助の扱いです)。
  連続で流す場合は MOSFET の発熱 (I² × Rds(on) × 2 × デューティ) とヒートシンクの熱抵抗も確認してください。

## 発注用パネル (ミシン目, 4 種 1 枚)

モジュールと子基板 A / B / C を 1 枚 (**99.9 × 99.8mm**, 100 × 100mm 以内) に面付けしたデータです。

| | |
|---|---|
| 生成 | `cd hardware && python3 gen_panel.py` (基板は `hardware/panel/`, 製造データは `hardware/fab/mPBCH32M030DS0_panel.zip`) |
| 図 | `docs/pcb/mPBCH32M030DS0_panel_top.png` / `_bottom.png` |
| 切り離し | 2mm の溝 + タブ (マウスバイト: 穴 0.5mm, 0.8mm ピッチ, 基板側へ 0.25mm)。V カットは基板の高さがそろわないため不可 |
| 配置 | 左上に A・C (縦), その右に捨て桟, 右端に B (全高 99.5mm)。モジュールは横向きで A/C の下 |
| タブの位置 | 基板端から 1.0mm 以内に銅の無い区間だけ。A ↔ C ↔ 捨て桟は長辺の下寄り (A/C の右辺は J2 沿いの GND 配線があるため)、捨て桟 ↔ B は B の左辺上部、モジュールは上辺 (USB 寄り) を A へ・右の短辺を B へ |
| ベタ | 全基板で基板端から 1.0mm 後退 (`gen_pcb.py zone_edge`)。割っても銅が出ない |
| DRC (パネル) | 未接続 0・電気的エラー 0 (シルク警告のみ) |
| ガーバー | 銅 (表裏)・レジスト (表裏)・シルク (表裏)・ペースト (表裏, ステンシル用)・外形、ドリル (PTH / NPTH 別) |

JLCPCB へ発注するときの主な設定:

- Layers 2 / 1.6mm / FR-4 / HASL (with lead) / 1oz
- **Delivery Format: Panel by Customer**、**Different Design: 4**
- Remove Order Number: **Specify a location** (左の捨て桟に `JLCJLCJLCJLC` を置いています)
- ステンシル (必要なら): 表・裏それぞれ、ペーストのガーバーから作成

## コンデンサのサイズ (耐圧と容量から現実的なサイズを選定)

| 値 | サイズ | 品番 (例) | 用途 |
|---|---|---|---|
| 0.1µF/50V X7R | 1005 | Murata GRM155R71H104KE14D | デカップリング全般, VCAP, RST |
| 1µF/25V X5R | 1005 | Murata GRM155R61E105KA12D | +5V (78L05 出力) |
| 10nF/50V, 1nF/50V X7R | 1005 | Murata GRM155R71H103KA88D / GRM155R71H102KA01D | 分圧フィルタ |
| 1nF, 2.2nF, 30pF C0G | 1005 | Murata GRM1555C1H102JA01D / 222JA01D / 300JA01D | 電流アンプ・水晶 |
| 1µF/50V X5R | 1608 | Murata GRM188R61H105KAALD | VBUS (78L05 入力) |
| 2.2µF/25V X5R | 1608 | Murata GRM188R61E225KA12D | ブートストラップ ×4 |
| **4.7µF/16V X5R** | **1608** | Samsung CL10A475KO8NNNC | VDD33 (**Rev 0.3 の 1005 は入手性が悪いため 1608 に変更**) |
| **4.7nF/100V X7R** | **1608** | Samsung CL10B472KC8NNNC | USB シールド (100V は 1005 の量産品が少ないため 1608) |
| **10µF/25V X5R** | **2012** | Murata GRM21BR61E106KA73L | VDD8 (1608 の 25V/10µF は DC バイアスで実効容量が大きく落ちるため 2012) |
| **10µF/50V X5R** | **1206** | Murata GRM31CR61H106KA12L | VHV, VBUS, 各レッグ (50V/10µF は 1206 が量産の中心) |
| 100µF/25V, 47µF/35V 電解 | φ8 / φ6.3 × 6.2mm | Panasonic EEE-FK1E101P / EEE-FK1V470P | バルク (子基板) |

いずれも Digi-Key / Mouser / LCSC などで流通している量産品番です (2026-09 時点の検索結果)。
Murata GRM188R61A475KE15D (4.7µF 1608) は生産終了のため採用していません。
DC バイアスで実効容量が下がる箇所 (VHV 24V, ブートストラップ 10V) は、耐圧に余裕のある品を選んでいます。

## 検証状況

| 項目 | 結果 |
|---|---|
| 回路図 (4 プロジェクト, KiCad 8.0.9) | `verify_netlist.py`: モジュール 83/83, 子基板 A/B/C 58/58 ネット一致 |
| 部品の重なり | courtyard 干渉なし (同一面) / 反対面の THT 穴との干渉なし / 基板外へのはみ出しなし |
| DRC | 子基板 A/B/C: 未接続 0・電気的エラー 0。**MCU モジュール: 未接続 0・電気的エラー 0** (下記) ([pcb/drc_summary.md](pcb/drc_summary.md)) |
| 製造データ | `hardware/fab/<基板名>.zip` (ガーバー, ドリル + 図, 両面の部品座標 CSV) |

## MCU モジュールの配線

QFN48 (0.35mm ピッチ) と 42 本の端子列の間は 2 層では混み合うため、水晶 Y1 と負荷容量 C131/C132 を
QFN 下辺の XI/XO (8/9 番ピン) 直下の裏面へ置き、表の下辺ピン 1〜7 の引き出しを空けて自動配線を通しきっています。
線幅・間隙 0.127mm / ビア 0.6mm (穴 0.3mm) で、JLCPCB の 2 層標準の範囲です。

- 以前の 20.32mm 幅 (8 マス) 版は 0.127mm では未接続が 20 か所前後残り (0.10mm なら通るが 2 層標準外)、廃止しました。
- 手直し用のベタなし版: `hardware/nopour/`
- ベタなし版は配線とビアを残し、GND ベタ・大電流の太らせたベタ・スティッチングビアだけを外したものです。
  手直しするときに使い、終わったら GND ベタ (両面) を引き直し、ステッチングビアを打ってください。

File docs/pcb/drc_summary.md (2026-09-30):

# DRC 結果 (KiCad 8 pcbnew, gen_pcb.py 実行時に自動生成)

ルール: 2 層 / 最小線幅・間隙 0.127mm / ビア 0.6mm (穴 0.3mm, 大電流 0.8mm, QFN サーマルビア 0.2mm) / 基板端 0.25mm (ベタは 1.0mm)。
「lib_footprint_issues」(ライブラリ照合) はスクリプト生成のため対象外。

| 基板 | 電気的エラー (配線・間隙・未接続など) | 警告 (シルク等, 製造時にクリップされるもの) |
|---|---|---|
| mPBCH32M030DS0 | なし | silk_edge_clearance 6, silk_over_copper 13, silk_overlap 26 |
| mPBCH32M030DS0_PWR_A | なし | silk_edge_clearance 2, silk_over_copper 69, silk_overlap 9 |
| mPBCH32M030DS0_PWR_B | なし | silk_edge_clearance 7, silk_over_copper 89, silk_overlap 7, track_dangling 4 |
| mPBCH32M030DS0_PWR_C | なし | silk_edge_clearance 2, silk_over_copper 57, silk_overlap 8, track_dangling 1 |

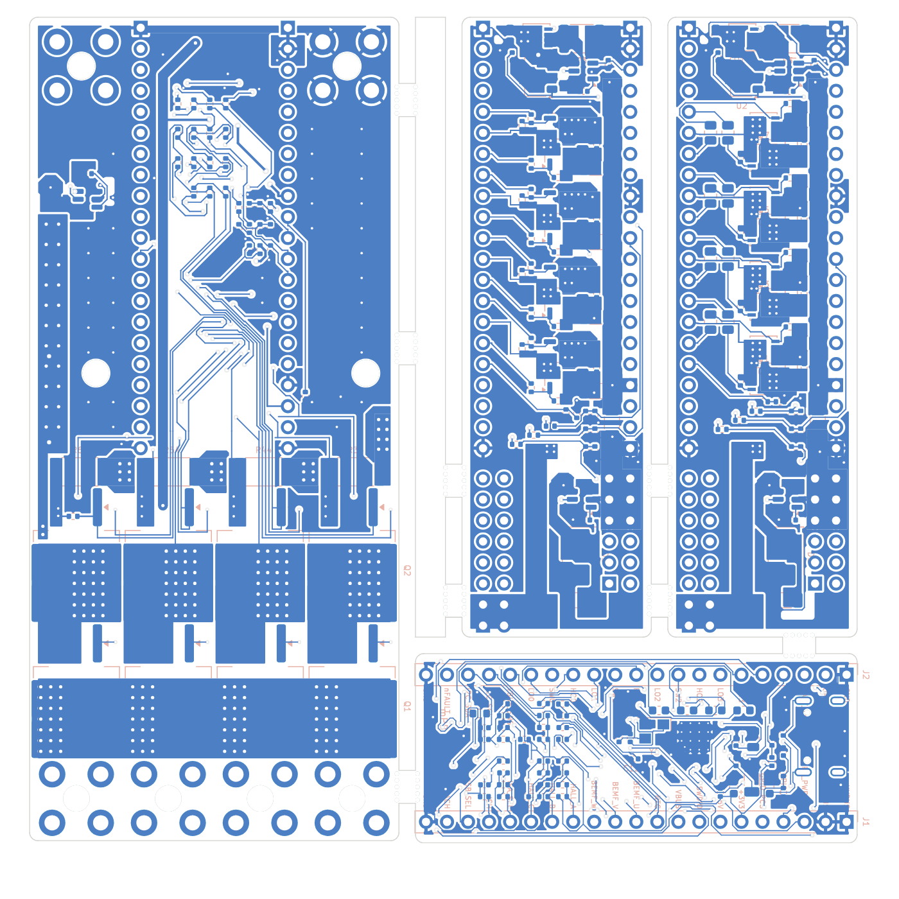
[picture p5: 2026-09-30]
docs/pcb/mPBCH32M030DS0_panel_bottom.png

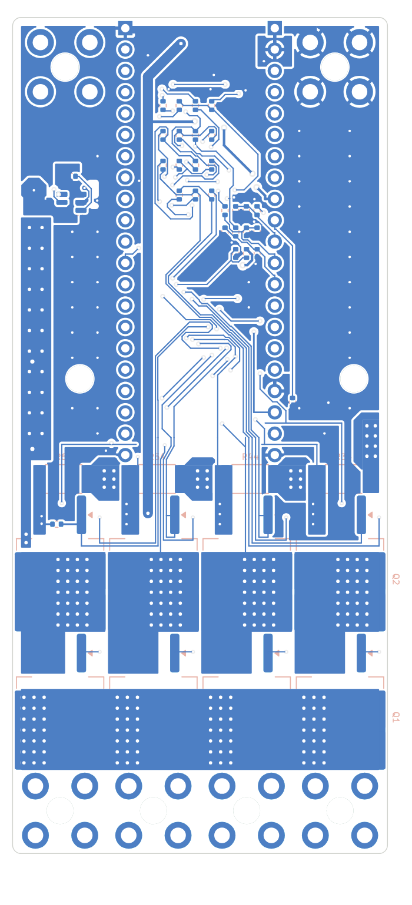
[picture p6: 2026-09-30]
docs/pcb/mPBCH32M030DS0_PWR_B_bottom.png

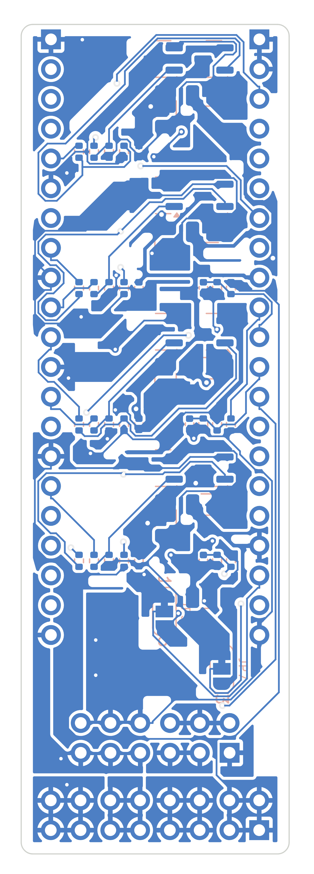
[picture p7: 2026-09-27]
docs/pcb/mPBCH32M030DS0_PWR_C_bottom.png

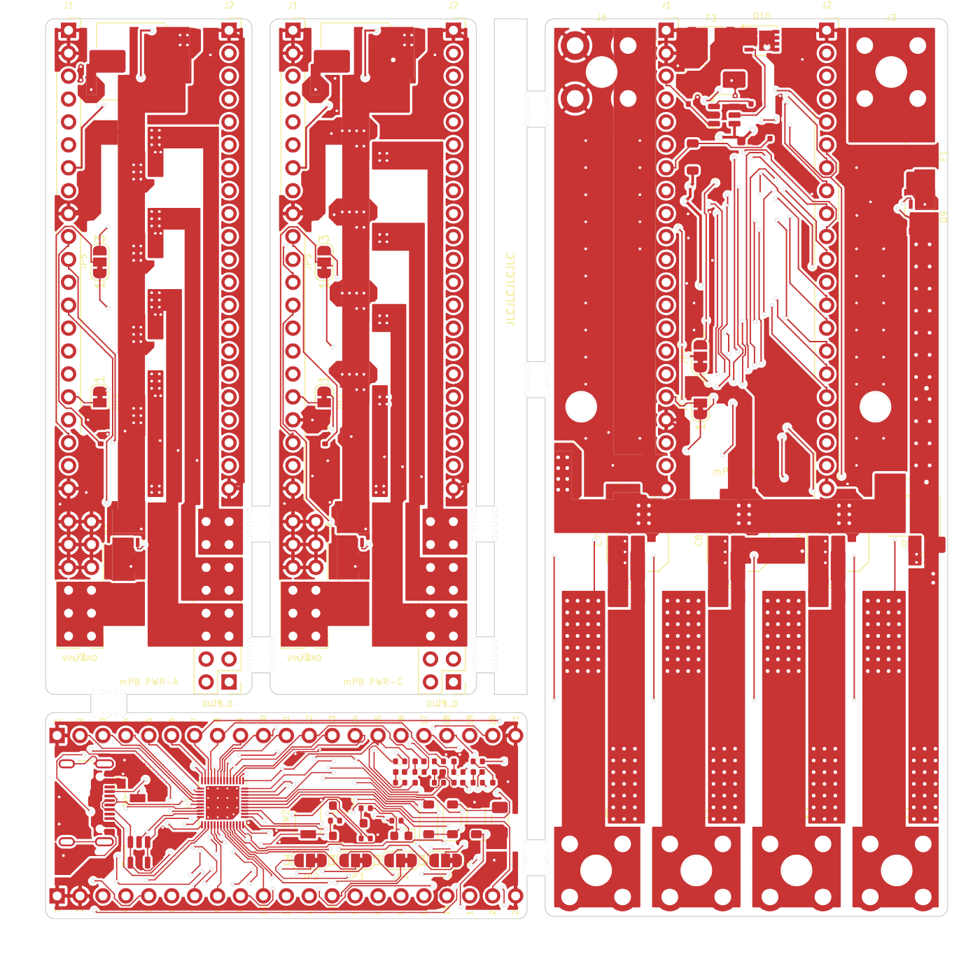
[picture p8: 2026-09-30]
docs/pcb/mPBCH32M030DS0_panel_top.png

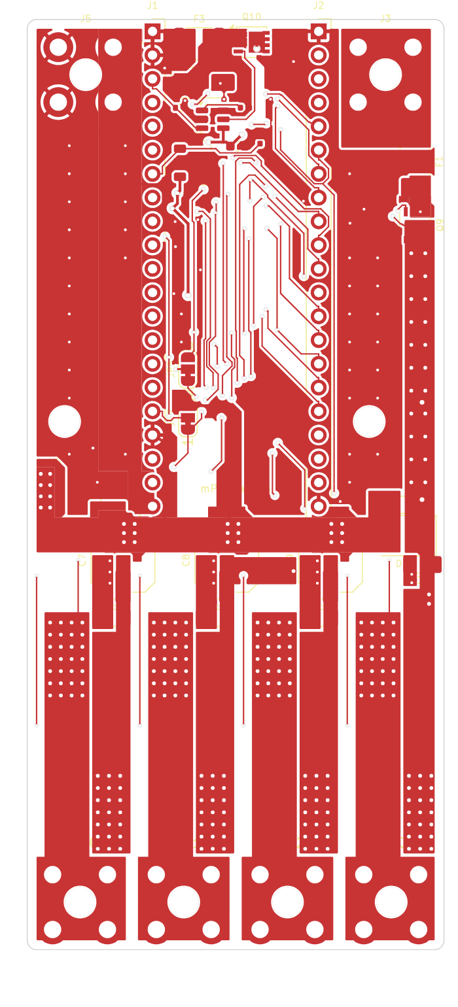
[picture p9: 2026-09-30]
docs/pcb/mPBCH32M030DS0_PWR_B_top.png

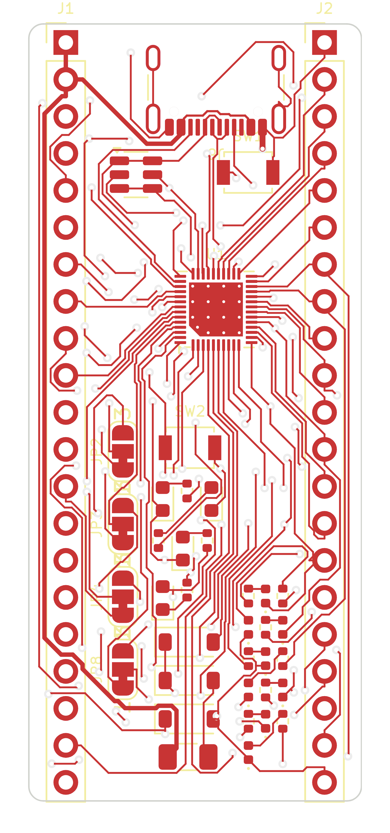
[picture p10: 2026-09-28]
docs/pcb/nopour/mPBCH32M030DS0_top.png

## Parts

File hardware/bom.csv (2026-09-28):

Qty | References | Value | Footprint | MPN / 備考 | DNP
2 | C7 C16 | 10nF/50V | Capacitor_SMD:C_0402_1005Metric | Murata GRM155R71H103KA88D (X7R 1005)
1 | C10 | 10uF/50V | Capacitor_SMD:C_1206_3216Metric | Murata GRM31CR61H106KA12L (X5R 1206)
7 | C11 C13 C15 C18 C103 C105 C133 | 0.1uF/50V | Capacitor_SMD:C_0402_1005Metric | Murata GRM155R71H104KE14D (X7R 1005)
1 | C12 | 10uF/25V | Capacitor_SMD:C_0805_2012Metric | Murata GRM21BR61E106KA73L (X5R 2012)
1 | C14 | 4.7uF/16V | Capacitor_SMD:C_0603_1608Metric | Samsung CL10A475KO8NNNC (X5R 1608)
1 | C17 | 1nF C0G | Capacitor_SMD:C_0402_1005Metric | Murata GRM1555C1H102JA01D (C0G 1005)
2 | C19 C20 | 2.2nF C0G | Capacitor_SMD:C_0402_1005Metric | Murata GRM1555C1H222JA01D (C0G 1005)
4 | C21 C22 C23 C24 | 2.2uF/25V | Capacitor_SMD:C_0603_1608Metric | Murata GRM188R61E225KA12D (X5R 1608)
4 | C100 C101 C102 C120 | 1nF/50V | Capacitor_SMD:C_0402_1005Metric | Murata GRM155R71H102KA01D (X7R 1005)
1 | C130 | 4.7nF/100V | Capacitor_SMD:C_0603_1608Metric | Samsung CL10B472KC8NNNC (X7R 100V 1608)
2 | C131 C132 | 30pF C0G | Capacitor_SMD:C_0402_1005Metric | Murata GRM1555C1H300JA01D (C0G 1005)
1 | D2 | GREEN 5V | LED_SMD:LED_0603_1608Metric | 1608 チップ LED
1 | D3 | GREEN STAT | LED_SMD:LED_0603_1608Metric | 1608 チップ LED
1 | D4 | MMSZ5254B 27V | Diode_SMD:D_SOD-123 | MMSZ5254B (27V 500mW, VHV 絶対最大 30V の保護)
2 | D5 D6 | B5819W | Diode_SMD:D_SOD-123 | B5819W (40V 1A ショットキー)
1 | D7 | RED VBUS | LED_SMD:LED_0603_1608Metric | 1608 チップ LED
1 | D8 | GREEN 3V3 | LED_SMD:LED_0603_1608Metric | 1608 チップ LED
1 | D10 | RED GH0 | LED_SMD:LED_0402_1005Metric | 1005 チップ LED (例: Kingbright APHHS1005)
1 | D11 | GREEN GL0 | LED_SMD:LED_0402_1005Metric | 1005 チップ LED (例: Kingbright APHHS1005)
1 | D12 | RED GH1 | LED_SMD:LED_0402_1005Metric | 1005 チップ LED (例: Kingbright APHHS1005)
1 | D13 | GREEN GL1 | LED_SMD:LED_0402_1005Metric | 1005 チップ LED (例: Kingbright APHHS1005)
1 | D14 | RED GH2 | LED_SMD:LED_0402_1005Metric | 1005 チップ LED (例: Kingbright APHHS1005)
1 | D15 | GREEN GL2 | LED_SMD:LED_0402_1005Metric | 1005 チップ LED (例: Kingbright APHHS1005)
1 | D16 | RED GH3 | LED_SMD:LED_0402_1005Metric | 1005 チップ LED (例: Kingbright APHHS1005)
1 | D17 | GREEN GL3 | LED_SMD:LED_0402_1005Metric | 1005 チップ LED (例: Kingbright APHHS1005)
1 | F2 | PTC 0.5A | Fuse:Fuse_1206_3216Metric | ポリスイッチ 0.5A 1206 (例: Bourns MF-NSMF050)
1 | J1 | EDGE_L | Connector_PinHeader_2.54mm:PinHeader_1x21_P2.54mm_Vertical | 2.54mm 1x21 ピンヘッダ (裏 or 表から実装)
1 | J2 | EDGE_R | Connector_PinHeader_2.54mm:PinHeader_1x21_P2.54mm_Vertical | 2.54mm 1x21 ピンヘッダ (裏 or 表から実装)
1 | J8 | USB-C | Connector_USB:USB_C_Receptacle_GCT_USB4105-xx-A_16P_TopMnt_Horizontal | GCT USB4105-GF-A (USB-C 16P)
1 | JP2 | SEL_U | Jumper:SolderJumper-3_P1.3mm_Bridged12_RoundedPad1.0x1.5mm_NumberLabels | はんだジャンパ 3 端子 (1-2 ブリッジ済み: 相電圧 / 2-3: ホール)
1 | JP3 | SEL_V | Jumper:SolderJumper-3_P1.3mm_Bridged12_RoundedPad1.0x1.5mm_NumberLabels | はんだジャンパ 3 端子 (1-2 ブリッジ済み: 相電圧 / 2-3: ホール)
1 | JP4 | SEL_W | Jumper:SolderJumper-3_P1.3mm_Bridged12_RoundedPad1.0x1.5mm_NumberLabels | はんだジャンパ 3 端子 (1-2 ブリッジ済み: 相電圧 / 2-3: ホール)
1 | JP8 | QII_SRC | Jumper:SolderJumper-3_P1.3mm_Bridged12_RoundedPad1.0x1.5mm_NumberLabels | はんだジャンパ 3 端子 (1-2 ブリッジ済み: TACH_IN / 2-3: バス電流リップル)
1 | R3 | 2.2k | Resistor_SMD:R_0402_1005Metric
1 | R4 | 15k | Resistor_SMD:R_0402_1005Metric
1 | R5 | 1.5k | Resistor_SMD:R_0402_1005Metric
1 | R7 | 120k 1% | Resistor_SMD:R_0402_1005Metric
1 | R8 | 10k 1% | Resistor_SMD:R_0402_1005Metric
1 | R10 | 47R | Resistor_SMD:R_0603_1608Metric
5 | R13 R101 R104 R107 R112 | 1k | Resistor_SMD:R_0402_1005Metric
1 | R14 | 12k 1% | Resistor_SMD:R_0402_1005Metric
1 | R15 | 1k 1% | Resistor_SMD:R_0402_1005Metric
4 | R16 R17 R18 R19 | 100R 1% | Resistor_SMD:R_0402_1005Metric
8 | R50 R51 R52 R53 R54 R55 R56 R57 | 22k | Resistor_SMD:R_0402_1005Metric
4 | R100 R103 R106 R123 | 4.7k | Resistor_SMD:R_0402_1005Metric
1 | R110 | 10k | Resistor_SMD:R_0402_1005Metric |  | DNP
3 | R111 R122 R131 | 10k | Resistor_SMD:R_0402_1005Metric
2 | R114 R115 | 4.7k | Resistor_SMD:R_0402_1005Metric |  | DNP
1 | R120 | 470R | Resistor_SMD:R_0402_1005Metric
1 | R130 | 1M | Resistor_SMD:R_0402_1005Metric
1 | SW1 | RESET | Button_Switch_SMD:SW_SPST_B3U-1000P | Omron B3U-1000P (3x2.5mm SMD タクト, 上押し)
1 | SW2 | USER/BOOT | Button_Switch_SMD:SW_SPST_B3U-1000P | Omron B3U-1000P (3x2.5mm SMD タクト, 上押し)
1 | U1 | CH32M030C8U7 | CH32M030DS0_QFN48:CH32M030DS0_QFN48 | WCH CH32M030C8U7 (QFN48 5x5mm 0.35mm pitch)
1 | U3 | USBLC6-2SC6 | Package_TO_SOT_SMD:SOT-23-6 | ST USBLC6-2SC6 (D+/D- ESD 保護, 基準は +3V3)
1 | Y1 | 8MHz CL=20pF | Crystal:Crystal_SMD_3225-4Pin_3.2x2.5mm | 8MHz 3225 4pad, CL=20pF, ESR≤60Ω (例: Abracon ABM8-8.000MHZ-B2-T)

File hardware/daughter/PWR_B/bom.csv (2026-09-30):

Qty | References | Value | Footprint | MPN / 備考 | DNP
5 | C1 C31 C41 C51 C61 | 10uF/50V | Capacitor_SMD:C_1206_3216Metric | Murata GRM31CR61H106KA12L (X5R 1206)
1 | C3 | 1uF/50V | Capacitor_SMD:C_0603_1608Metric | Murata GRM188R61H105KAALD (X5R 1608)
1 | C4 | 1uF/25V | Capacitor_SMD:C_0402_1005Metric | Murata GRM155R61E105KA12D (X5R 1005)
6 | C5 C6 C30 C40 C50 C60 | 0.1uF/50V | Capacitor_SMD:C_0402_1005Metric | Murata GRM155R71H104KE14D (X7R 1005)
3 | C7 C8 C9 | 47uF/35V | Capacitor_SMD:CP_Elec_6.3x5.9 | Panasonic EEE-FK1V470P (6.3x6.1mm)
3 | C71 C72 C73 | 1nF/50V | Capacitor_SMD:C_0402_1005Metric | Murata GRM155R71H102KA01D (X7R 1005)
1 | D1 | SMBJ24A | Diode_SMD:D_SMB | SMBJ24A (Vwm 24V)
1 | D9 | SMAJ20A | Diode_SMD:D_SMA | SMAJ20A (USB 側サージ)
1 | F1 | 10A | mPB:Fuse_Littelfuse_NANO2_2410 | Littelfuse 0451010.MRL (NANO2 2410, 10A 速断)
1 | F3 | 5A | Fuse:Fuse_1812_4532Metric | 1812 5A 速断ヒューズ (例: Bourns SF-1812F500)
2 | H1 H2 | HEATSINK_M3 | MountingHole:MountingHole_3.2mm_M3 | ヒートシンク固定用 M3 穴 (非めっき)
1 | J1 | SOCK_L | Connector_PinSocket_2.54mm:PinSocket_1x21_P2.54mm_Vertical | 2.54mm 1x21 ピンソケット (標準 8.5mm 高)
1 | J2 | SOCK_R | Connector_PinSocket_2.54mm:PinSocket_1x21_P2.54mm_Vertical | 2.54mm 1x21 ピンソケット (標準 8.5mm 高)
1 | J3 | VIN | TerminalBlock_Wuerth:Wuerth_REDCUBE-THR_WP-THRBU_74650073_THR | Würth REDCUBE THR WP-THRBU 74650073 (M3 貫通ネジ, 丸端子用, 定格 50A 以上)
1 | J5 | GND | TerminalBlock_Wuerth:Wuerth_REDCUBE-THR_WP-THRBU_74650073_THR | Würth REDCUBE THR WP-THRBU 74650073 (M3 貫通ネジ, 丸端子用, 定格 50A 以上)
1 | J40 | OUT0 | TerminalBlock_Wuerth:Wuerth_REDCUBE-THR_WP-THRBU_74650073_THR | Würth REDCUBE THR WP-THRBU 74650073 (M3 貫通ネジ, 丸端子用, 定格 50A 以上)
1 | J41 | OUT1 | TerminalBlock_Wuerth:Wuerth_REDCUBE-THR_WP-THRBU_74650073_THR | Würth REDCUBE THR WP-THRBU 74650073 (M3 貫通ネジ, 丸端子用, 定格 50A 以上)
1 | J42 | OUT2 | TerminalBlock_Wuerth:Wuerth_REDCUBE-THR_WP-THRBU_74650073_THR | Würth REDCUBE THR WP-THRBU 74650073 (M3 貫通ネジ, 丸端子用, 定格 50A 以上)
1 | J43 | OUT3 | TerminalBlock_Wuerth:Wuerth_REDCUBE-THR_WP-THRBU_74650073_THR | Würth REDCUBE THR WP-THRBU 74650073 (M3 貫通ネジ, 丸端子用, 定格 50A 以上)
1 | JP5 | ISEL_B | Jumper:SolderJumper-3_P1.3mm_Bridged12_RoundedPad1.0x1.5mm_NumberLabels | はんだジャンパ 3 端子 (1-2 ブリッジ済み: HB1 / 2-3: HB2)
1 | JP7 | ISEL_A | Jumper:SolderJumper-3_P1.3mm_Bridged12_RoundedPad1.0x1.5mm_NumberLabels | はんだジャンパ 3 端子 (1-2 ブリッジ済み: HB0 レッグ / 2-3: バス電流)
8 | Q1 Q2 Q3 Q4 Q5 Q6 Q7 Q8 | TKR74F04PB | Package_TO_SOT_SMD:TO-263-2 | Toshiba TKR74F04PB,LQ (40V 0.74mΩ TO-220SM(W)) ※ランドは TO-263-2 で暫定
1 | Q9 | TPN2R304PL | Package_SO:Vishay_PowerPAK_1212-8_Single | Toshiba TPN2R304PL,L1Q (40V 2.3mΩ, 理想ダイオード)
1 | Q10 | TPN1R603PL | Package_SO:Vishay_PowerPAK_1212-8_Single | Toshiba TPN1R603PL,L1Q (USB 側 理想ダイオード)
1 | R6 | 100k | Resistor_SMD:R_0402_1005Metric
1 | R11 | 180k 1% | Resistor_SMD:R_0402_1005Metric
1 | R12 | 10k 1% | Resistor_SMD:R_0402_1005Metric
8 | R30 R32 R40 R42 R50 R52 R60 R62 | 22R | Resistor_SMD:R_0402_1005Metric
8 | R31 R33 R41 R43 R51 R53 R61 R63 | 10k | Resistor_SMD:R_0402_1005Metric
5 | R34 R44 R54 R64 R70 | 10mR 1% 3W | Resistor_SMD:R_2512_6332Metric | 2512 3W (例: Bourns CRE2512-FZ-R010E-3)
3 | R71 R74 R77 | 47k 1% | Resistor_SMD:R_0402_1005Metric
3 | R72 R75 R78 | 3.3k 1% | Resistor_SMD:R_0402_1005Metric
1 | TH1 | 10k B3435 | Resistor_SMD:R_0402_1005Metric | NTC 10kΩ B3435 1005 (例: Murata NCP15XH103F03RC) — MOSFET 近傍
1 | U2 | 78L05 | Package_TO_SOT_SMD:SOT-89-3 | 78L05 (SOT-89, Vin ≤30V)
2 | U4 U5 | LM74700-Q1 | Package_TO_SOT_SMD:SOT-23-6 | TI LM74700QDBVRQ1

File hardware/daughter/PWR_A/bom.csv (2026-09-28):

Qty | References | Value | Footprint | MPN / 備考 | DNP
1 | C1 | 10uF/50V | Capacitor_SMD:C_1206_3216Metric | Murata GRM31CR61H106KA12L (X5R 1206)
1 | C3 | 1uF/50V | Capacitor_SMD:C_0603_1608Metric | Murata GRM188R61H105KAALD (X5R 1608)
1 | C4 | 1uF/25V | Capacitor_SMD:C_0402_1005Metric | Murata GRM155R61E105KA12D (X5R 1005)
6 | C5 C6 C30 C40 C50 C60 | 0.1uF/50V | Capacitor_SMD:C_0402_1005Metric | Murata GRM155R71H104KE14D (X7R 1005)
1 | C7 | 150uF/25V | Capacitor_SMD:CP_Elec_8x6.2 | Panasonic EEE-FK1E151P (8x6.2mm)
4 | C31 C41 C51 C61 | 10uF/25V | Capacitor_SMD:C_0805_2012Metric | Murata GRM219R61E106KA12D (X5R 0805, 厚さ 0.85mm)
3 | C71 C72 C73 | 1nF/50V | Capacitor_SMD:C_0402_1005Metric | Murata GRM155R71H102KA01D (X7R 1005)
1 | D1 | SMBJ16A | Diode_SMD:D_SMB | SMBJ16A (Vwm 16V)
1 | F1 | 7A | mPB:Fuse_Littelfuse_NANO2_2410 | Littelfuse 0451007.MRL (NANO2 2410, 7A 速断)
1 | F3 | 5A | Fuse:Fuse_1812_4532Metric | 1812 5A 速断ヒューズ (例: Bourns SF-1812F500)
1 | J1 | SOCK_L | Connector_PinSocket_2.54mm:PinSocket_1x21_P2.54mm_Vertical | 2.54mm 1x21 ピンソケット (標準 8.5mm 高)
1 | J2 | SOCK_R | Connector_PinSocket_2.54mm:PinSocket_1x21_P2.54mm_Vertical | 2.54mm 1x21 ピンソケット (標準 8.5mm 高)
1 | J3 | PWR_IN | Connector_PinHeader_2.54mm:PinHeader_2x06_P2.54mm_Vertical | 2.54mm 2x6 ピンヘッダ (1-6 = VIN, 7-12 = GND, 各 6 本並列)
1 | J4 | MOTOR | Connector_PinHeader_2.54mm:PinHeader_2x08_P2.54mm_Vertical | 2.54mm 2x8 ピンヘッダ (各出力 4 本並列)
1 | JP5 | ISEL_B | Jumper:SolderJumper-3_P1.3mm_Bridged12_RoundedPad1.0x1.5mm_NumberLabels | はんだジャンパ 3 端子 (1-2 ブリッジ済み: HB1 / 2-3: HB2)
1 | JP7 | ISEL_A | Jumper:SolderJumper-3_P1.3mm_Bridged12_RoundedPad1.0x1.5mm_NumberLabels | はんだジャンパ 3 端子 (1-2 ブリッジ済み: HB0 レッグ / 2-3: バス電流)
8 | Q1 Q2 Q3 Q4 Q5 Q6 Q7 Q8 | TPN1R603PL | Package_SO:Vishay_PowerPAK_1212-8_Single | Toshiba TPN1R603PL,L1Q (30V 1.6mΩ Qg 41nC)
1 | Q9 | TPN2R304PL | Package_SO:Vishay_PowerPAK_1212-8_Single | Toshiba TPN2R304PL,L1Q (40V 2.3mΩ, 理想ダイオード)
1 | Q10 | TPN1R603PL | Package_SO:Vishay_PowerPAK_1212-8_Single | Toshiba TPN1R603PL,L1Q (USB 側 理想ダイオード)
1 | R6 | 100k | Resistor_SMD:R_0402_1005Metric
1 | R11 | 110k 1% | Resistor_SMD:R_0402_1005Metric
1 | R12 | 10k 1% | Resistor_SMD:R_0402_1005Metric
8 | R30 R32 R40 R42 R50 R52 R60 R62 | 47R | Resistor_SMD:R_0805_2012Metric
8 | R31 R33 R41 R43 R51 R53 R61 R63 | 20k | Resistor_SMD:R_0402_1005Metric
5 | R34 R44 R54 R64 R70 | 10mR 1% 0.5W | Resistor_SMD:R_1206_3216Metric | 1206 0.5W (例: Yageo PE1206FRF7W0R01L)
3 | R71 R74 R77 | 20k 1% | Resistor_SMD:R_0402_1005Metric
3 | R72 R75 R78 | 3k 1% | Resistor_SMD:R_0402_1005Metric
1 | TH1 | 10k B3435 | Resistor_SMD:R_0402_1005Metric | NTC 10kΩ B3435 1005 (例: Murata NCP15XH103F03RC) — MOSFET 近傍
1 | U2 | 78L05 | Package_TO_SOT_SMD:SOT-89-3 | 78L05 (SOT-89, Vin ≤30V)
2 | U4 U5 | LM74700-Q1 | Package_TO_SOT_SMD:SOT-23-6 | TI LM74700QDBVRQ1

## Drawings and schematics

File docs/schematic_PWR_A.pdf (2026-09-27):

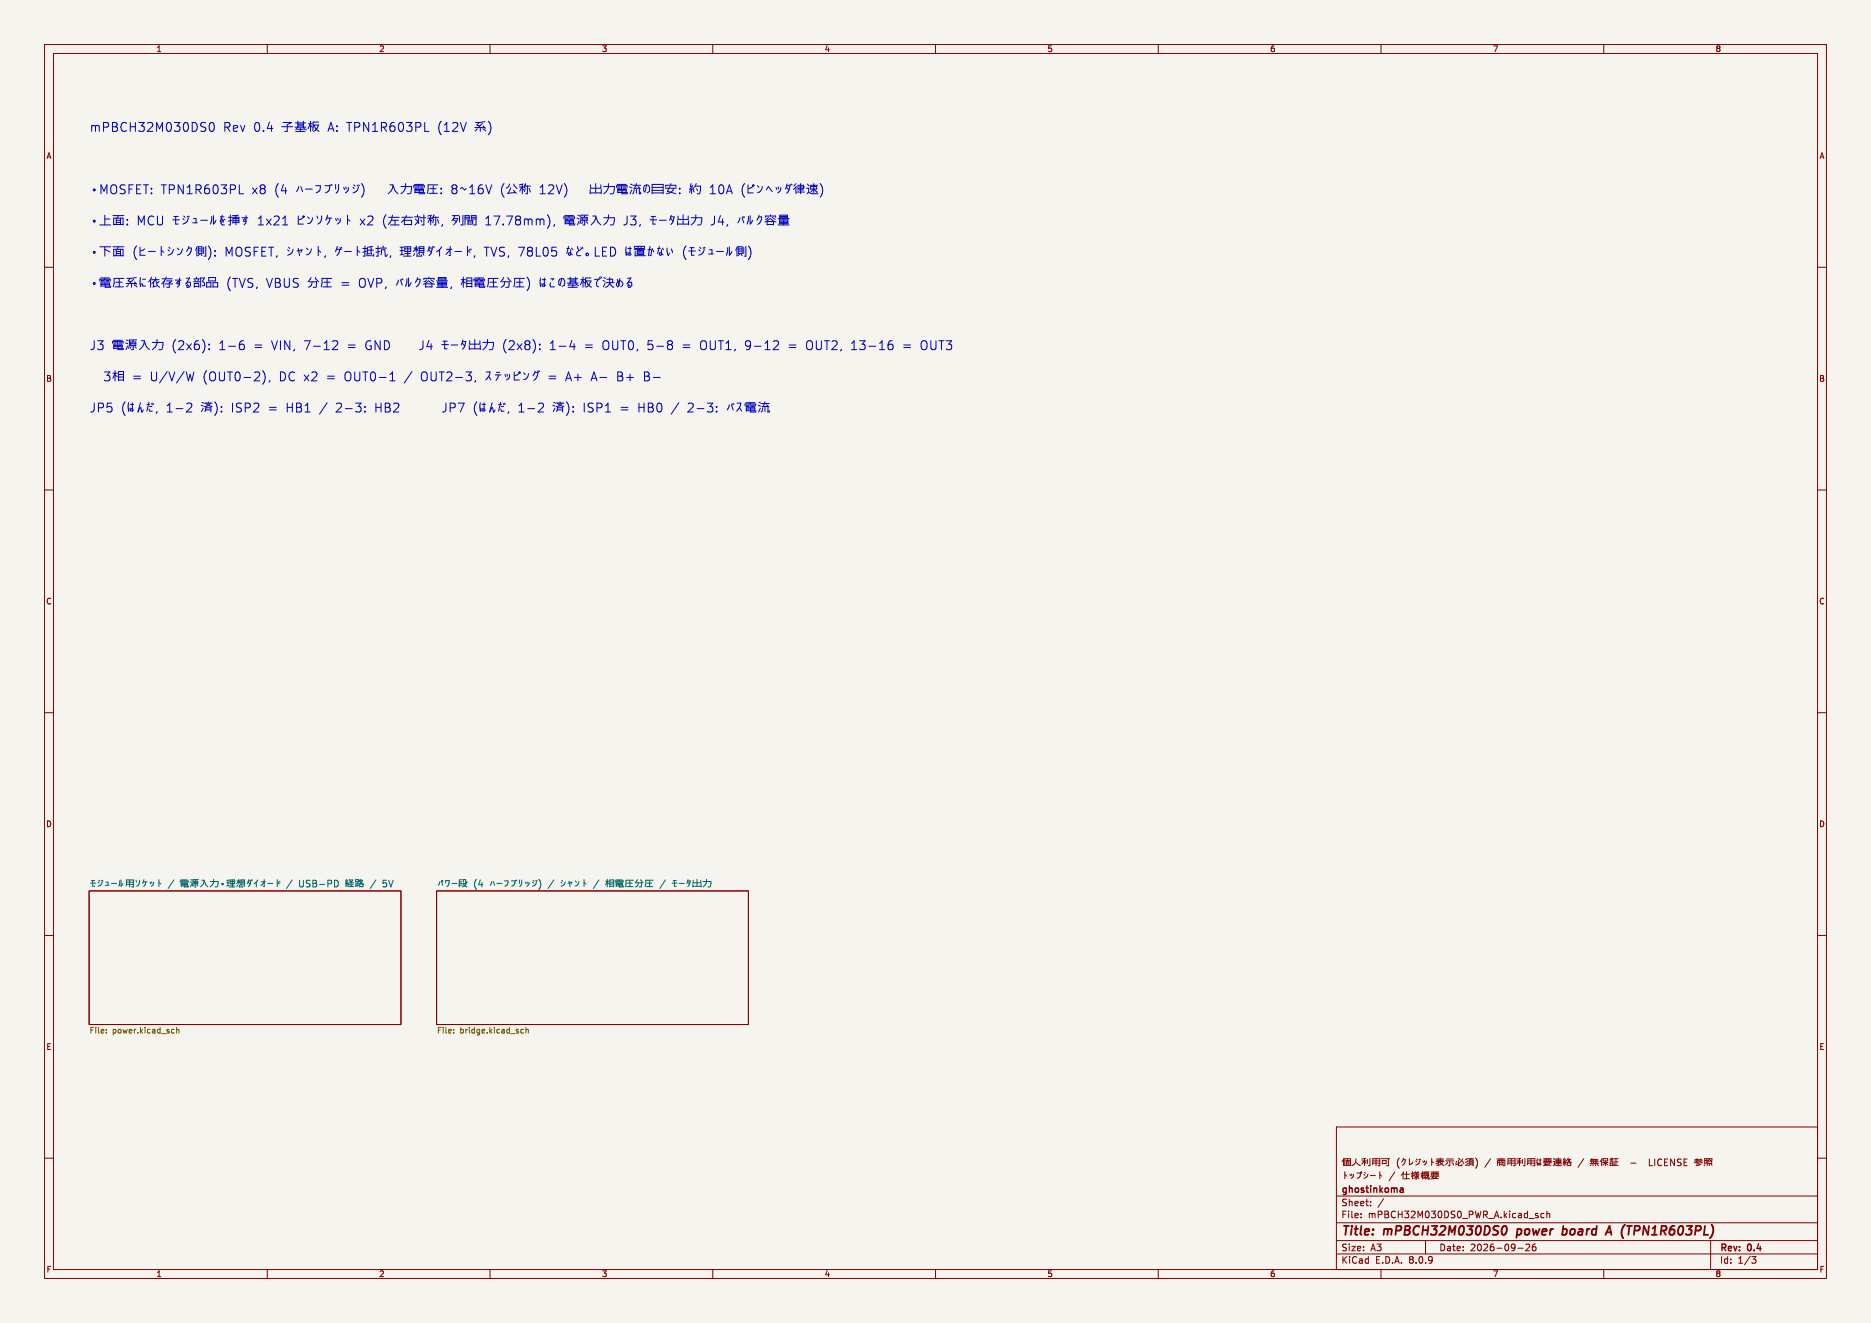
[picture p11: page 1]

þÿ0ûN—b þÿ(0Ò0ü0È0·0ó0¯Pt): MOSFET, þÿ0·0ã0ó0È, þÿ0²0ü0Èbµb—, þÿt`ó0À0¤0ª0ü0É, TVS, 78L05 þÿ0j0i0-

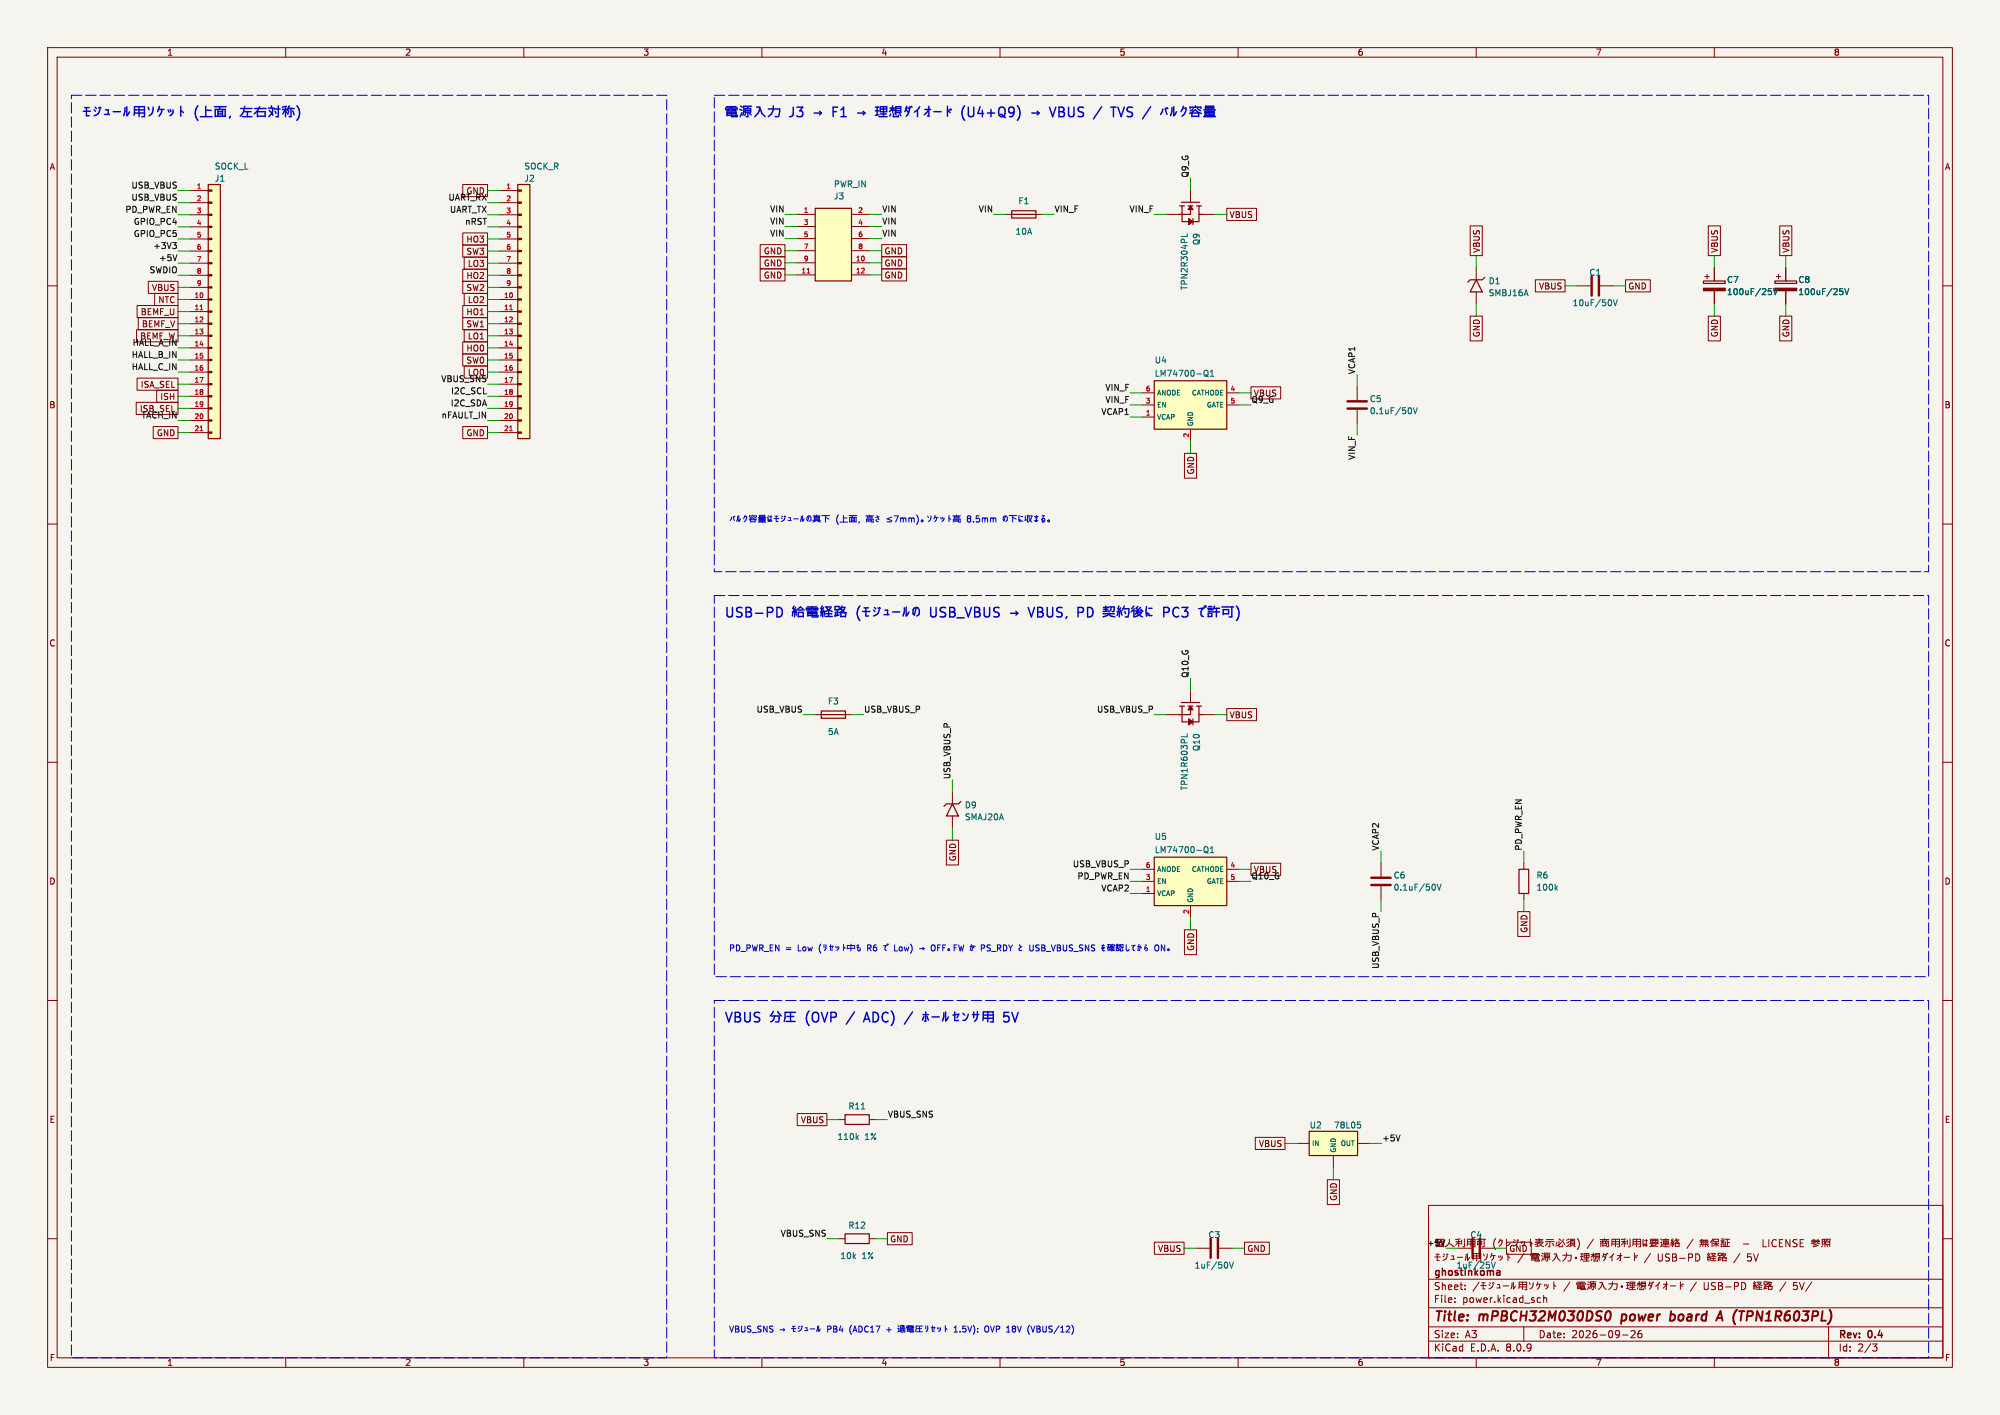
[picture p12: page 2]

2 EN 3 CATHODE 4 GATE 5 ANODE 6 U4

2 EN 3 CATHODE 4 GATE 5 ANODE 6 U5

PD_PWR_EN = Low þÿ(0ê0»0Ã0ÈN-0‚ R6 þÿ0gLow) þÿ!’þÿOFF0-

VBUS_SNS þÿ!’þÿ0â0¸0å0ü0ë PB4 (ADC17 + þÿ•N–ûW'0ê0»0Ã0È 1.5V): OVP 18V (VBUS/12)

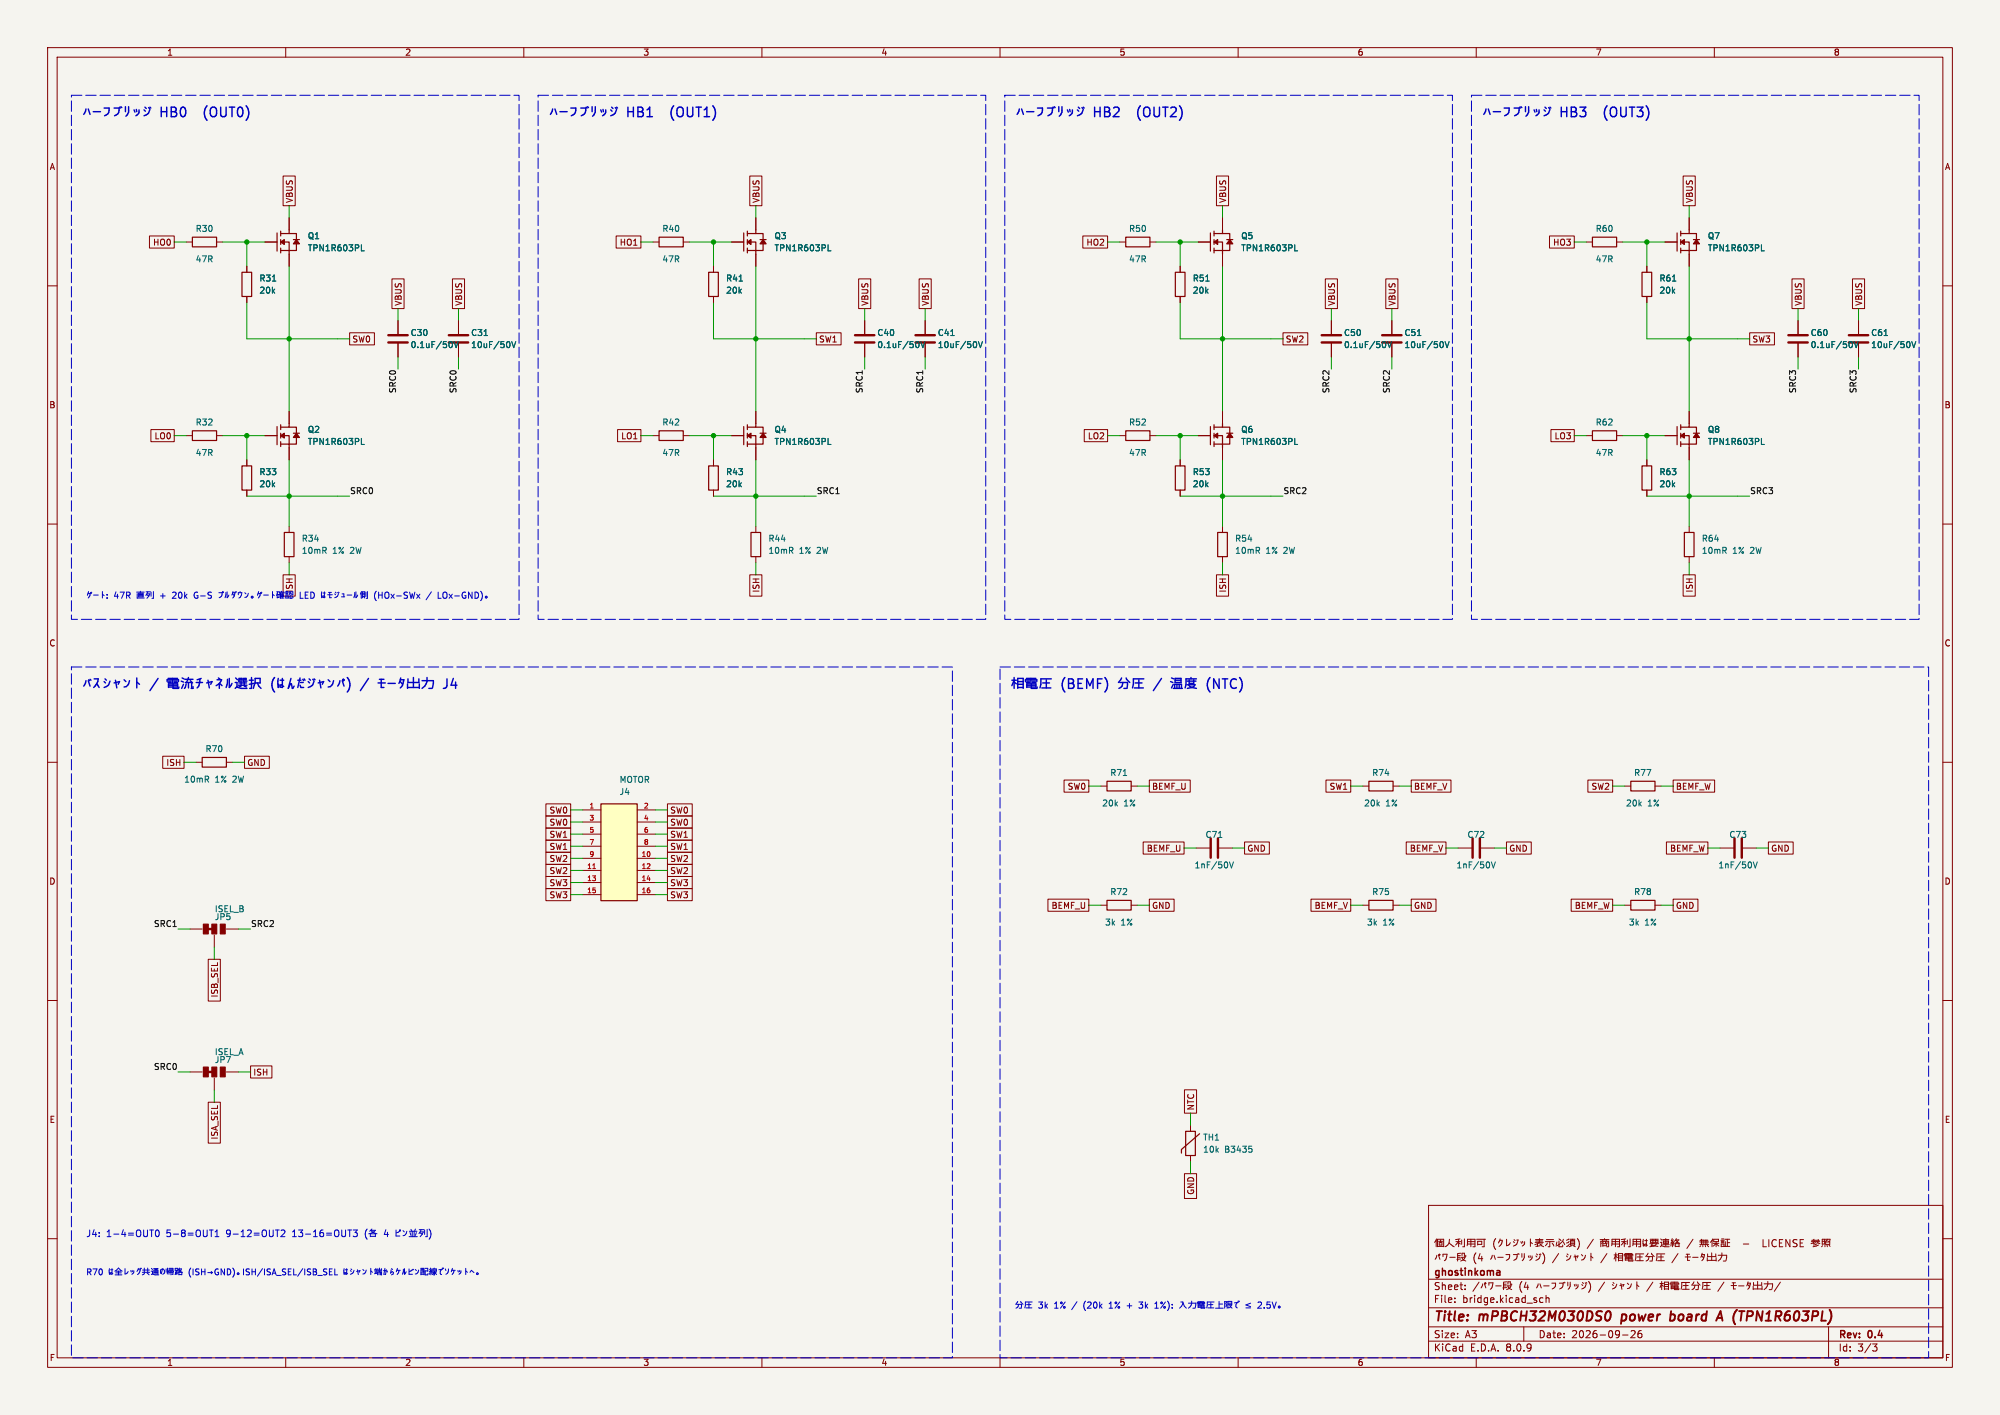
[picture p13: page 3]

0²0ü0ÈxºŠ• LED þÿ0o0â0¸0å0ü0ëPt (HOx-SWx / þÿLOx-GND)0-

þÿ0Ð0¹0·0ã0ó0È / þÿ–ûmA0Á0ã0Í0ë•xbž þÿ(0o0“0`0¸0ã0ó0Ñ) / þÿ0â0ü0¿QúR› J4

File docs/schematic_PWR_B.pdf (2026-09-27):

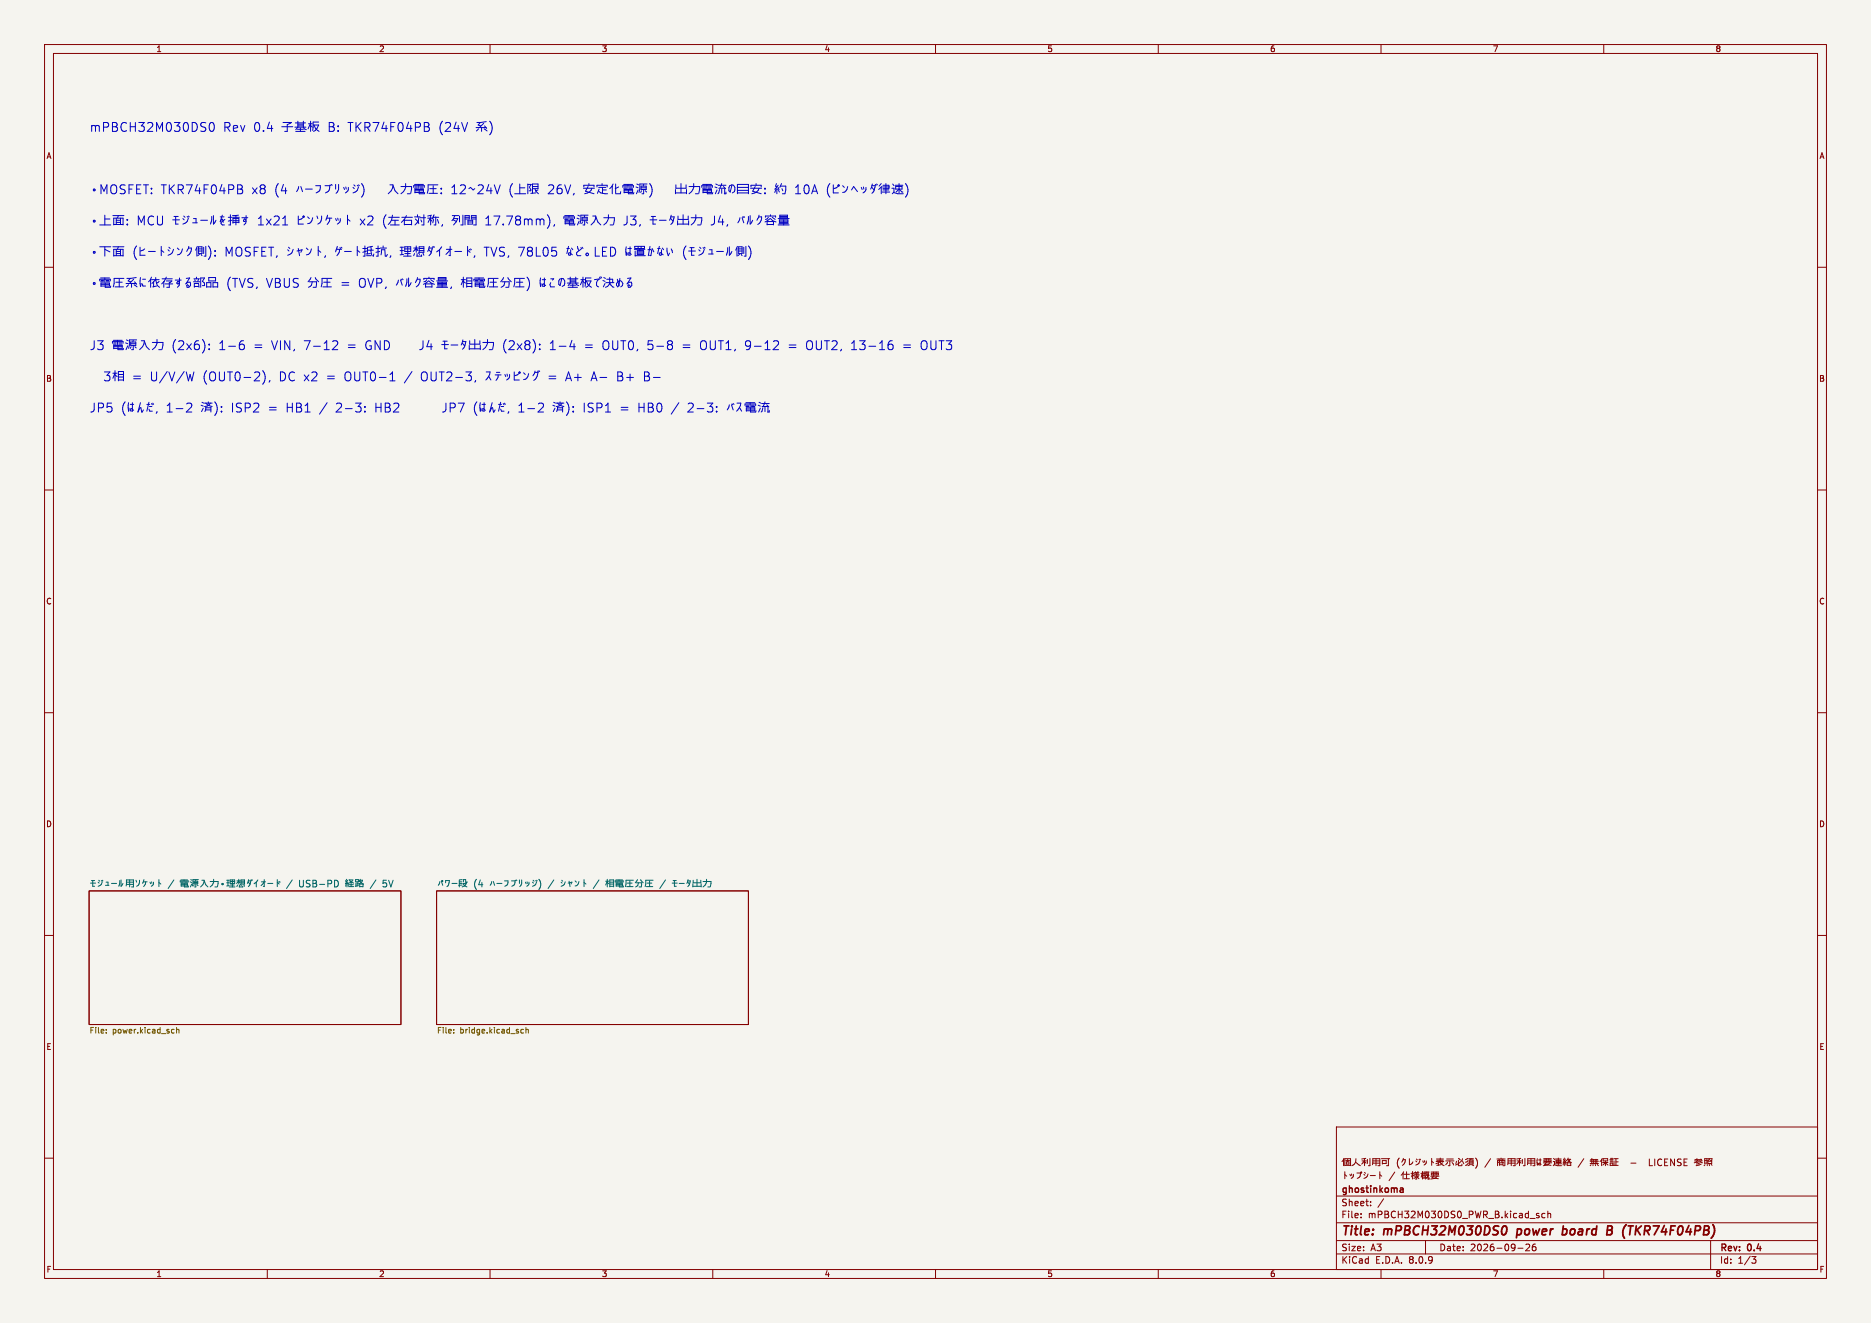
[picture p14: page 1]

–P26V, þÿ[‰[šS–ûn•) þÿQúR›–ûmA0nvî[‰: þÿ}10A þÿ(0Ô0ó0Ø0Ã0À_‹•)

þÿ0ûN—b þÿ(0Ò0ü0È0·0ó0¯Pt): MOSFET, þÿ0·0ã0ó0È, þÿ0²0ü0Èbµb—, þÿt`ó0À0¤0ª0ü0É, TVS, 78L05 þÿ0j0i0-

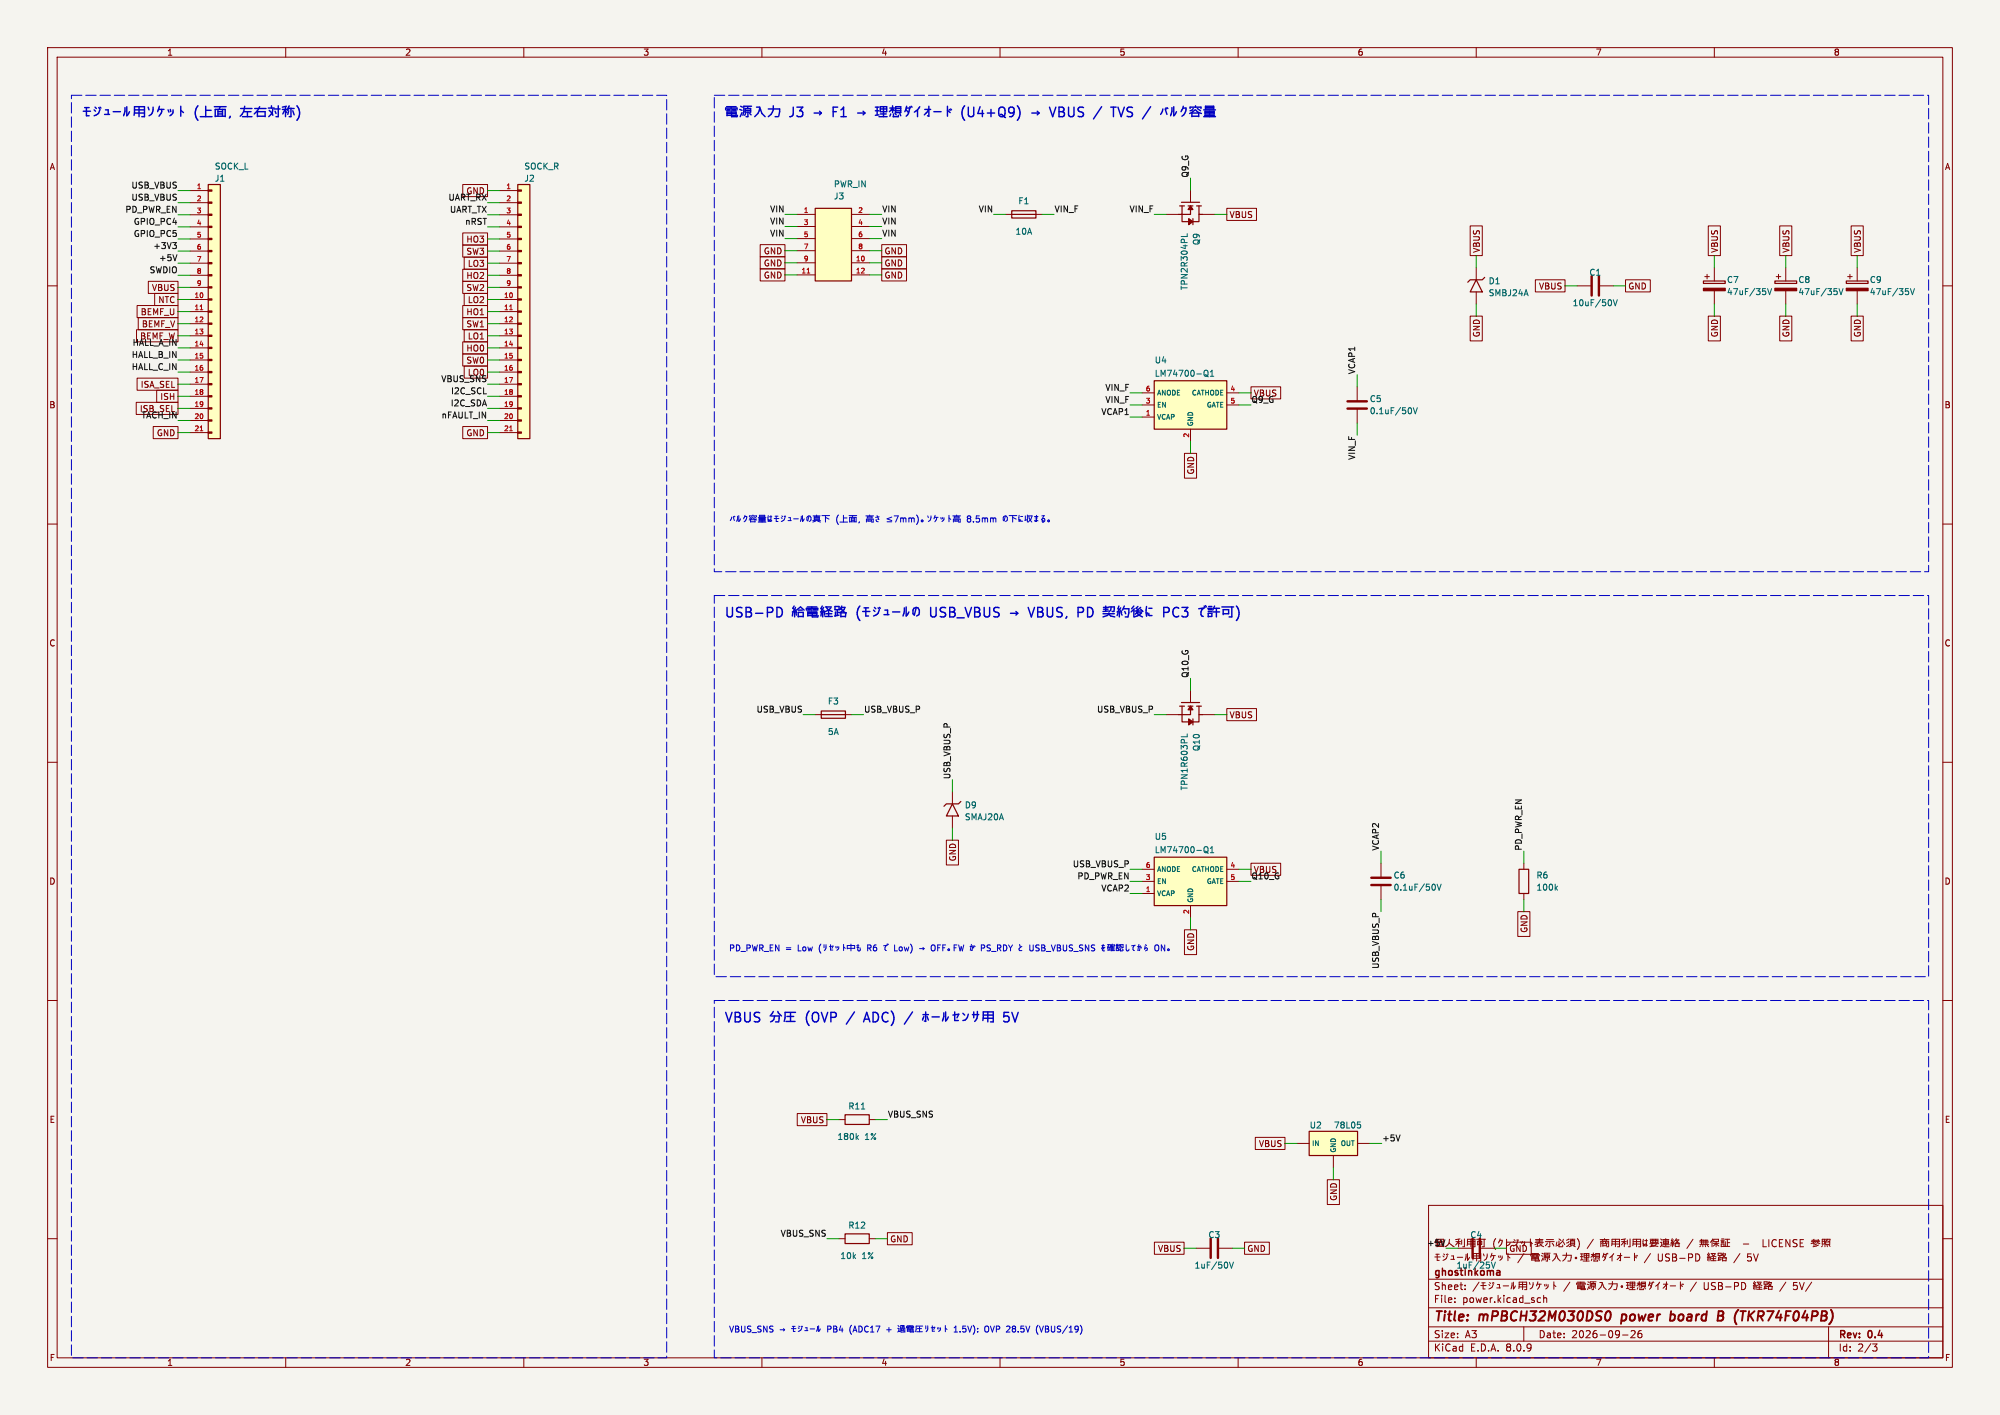
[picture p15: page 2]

2 EN 3 CATHODE 4 GATE 5 ANODE 6 U4

USB-PD þÿ}f–û}L•ï þÿ(0â0¸0å0ü0ë0n USB_VBUS þÿ!’VBUS, PD þÿYQ}_Œ0k PC3 þÿ0gŠ1Sï) PD_PWR_EN = Low þÿ(0ê0»0Ã0ÈN-0‚ R6 þÿ0gLow) þÿ!’þÿOFF0-

2 EN 3 CATHODE 4 GATE 5 ANODE 6 U5

VBUS þÿRW'(OVP / ADC) / þÿ0Û0ü0ë0»0ó0µu( 5V

VBUS_SNS þÿ!’þÿ0â0¸0å0ü0ë PB4 (ADC17 + þÿ•N–ûW'0ê0»0Ã0È 1.5V): OVP 28.5V (VBUS/19)

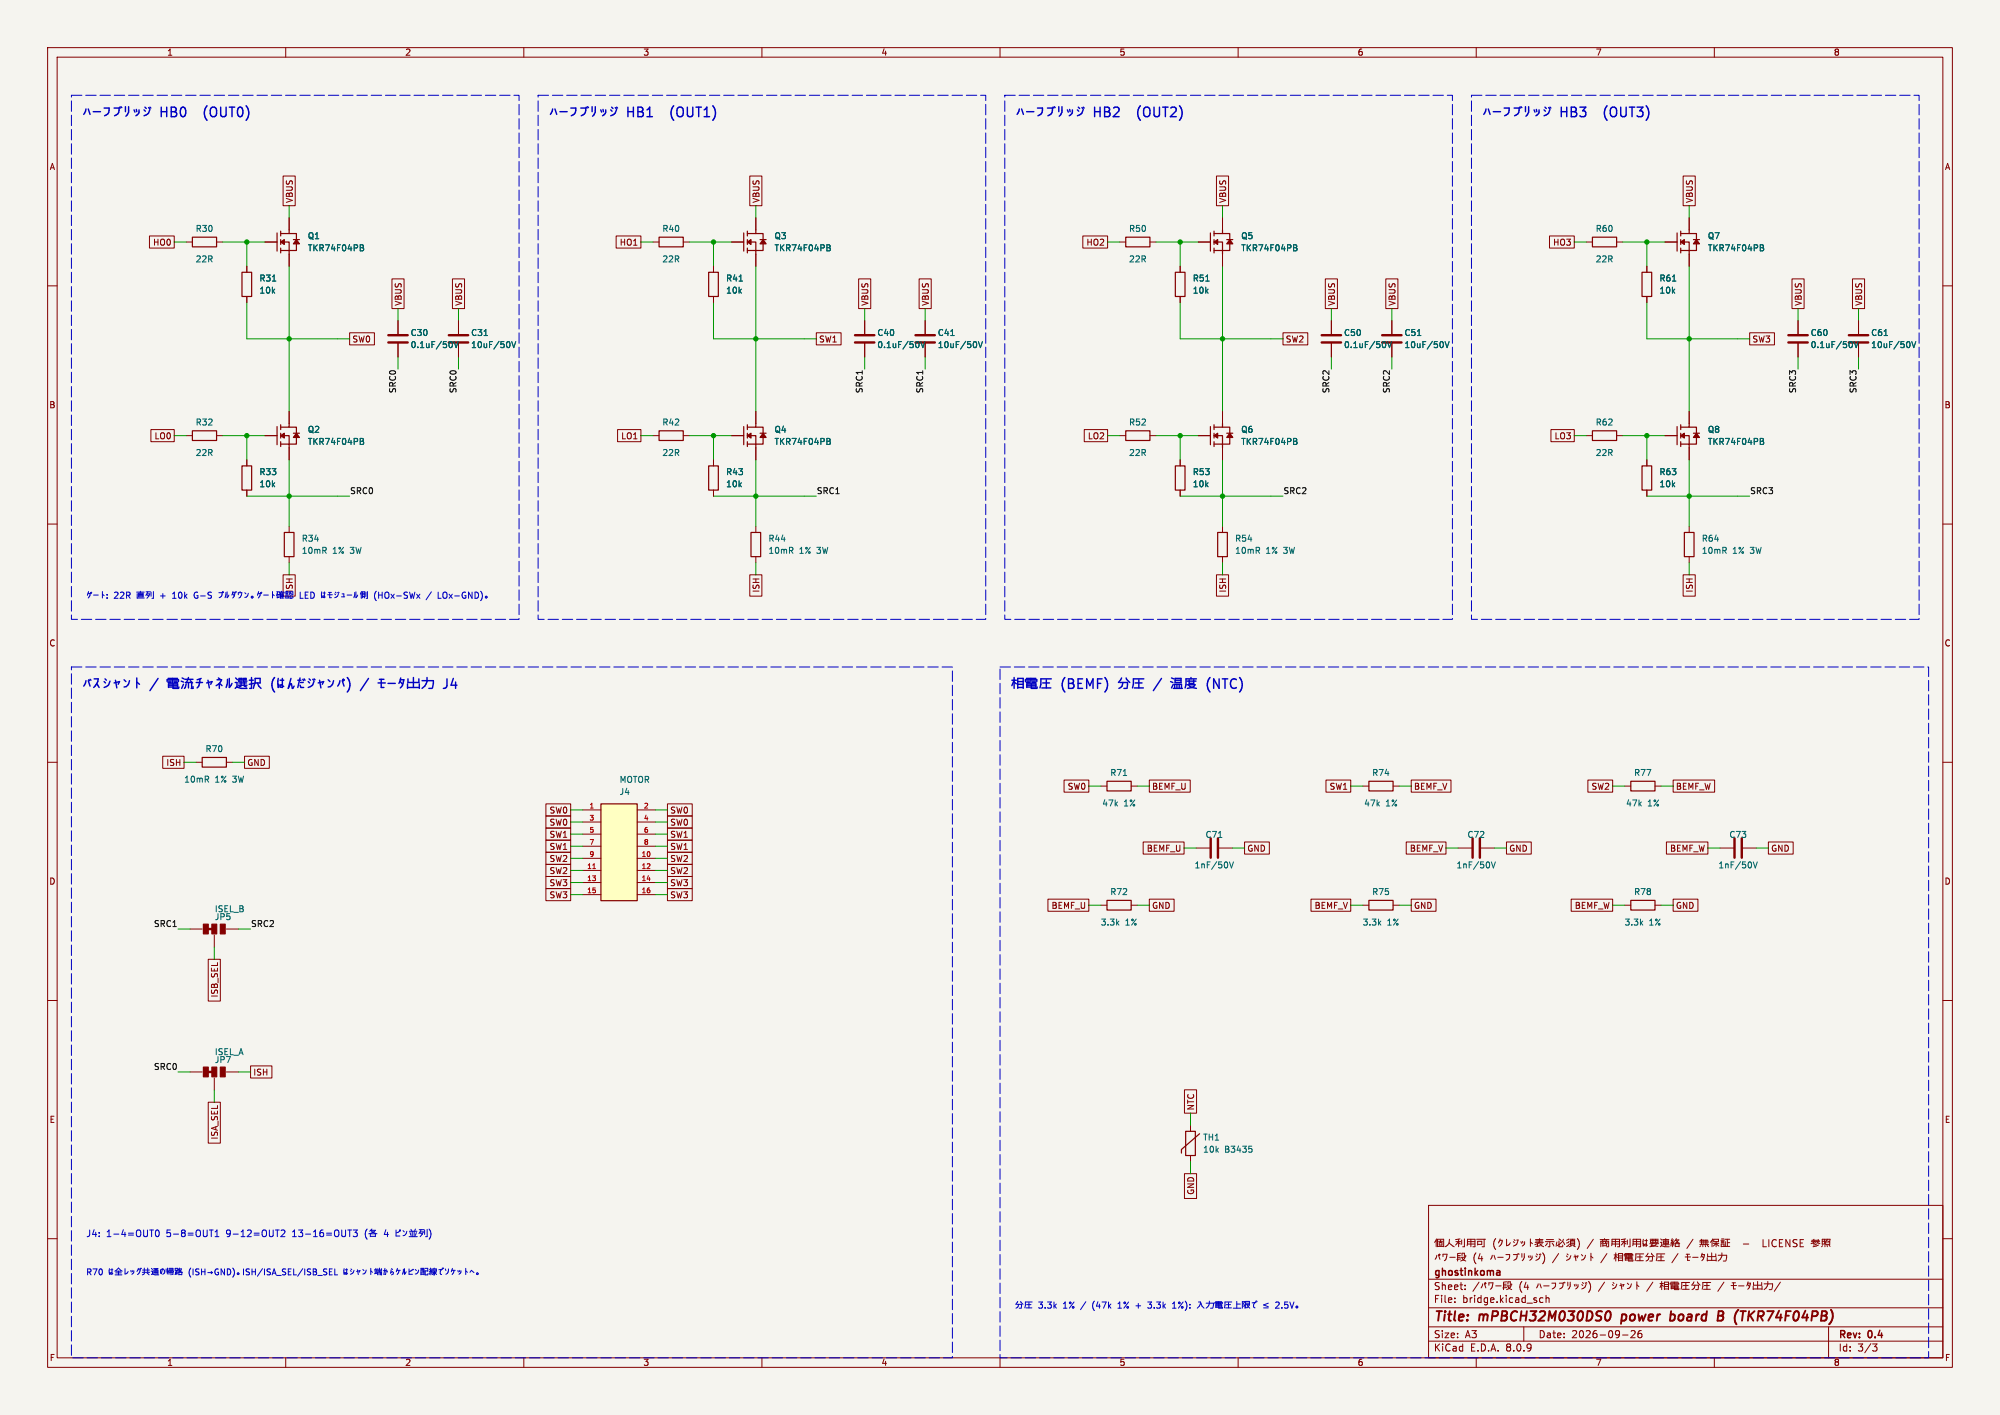
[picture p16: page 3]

0²0ü0ÈxºŠ• LED þÿ0o0â0¸0å0ü0ëPt (HOx-SWx / þÿLOx-GND)0-

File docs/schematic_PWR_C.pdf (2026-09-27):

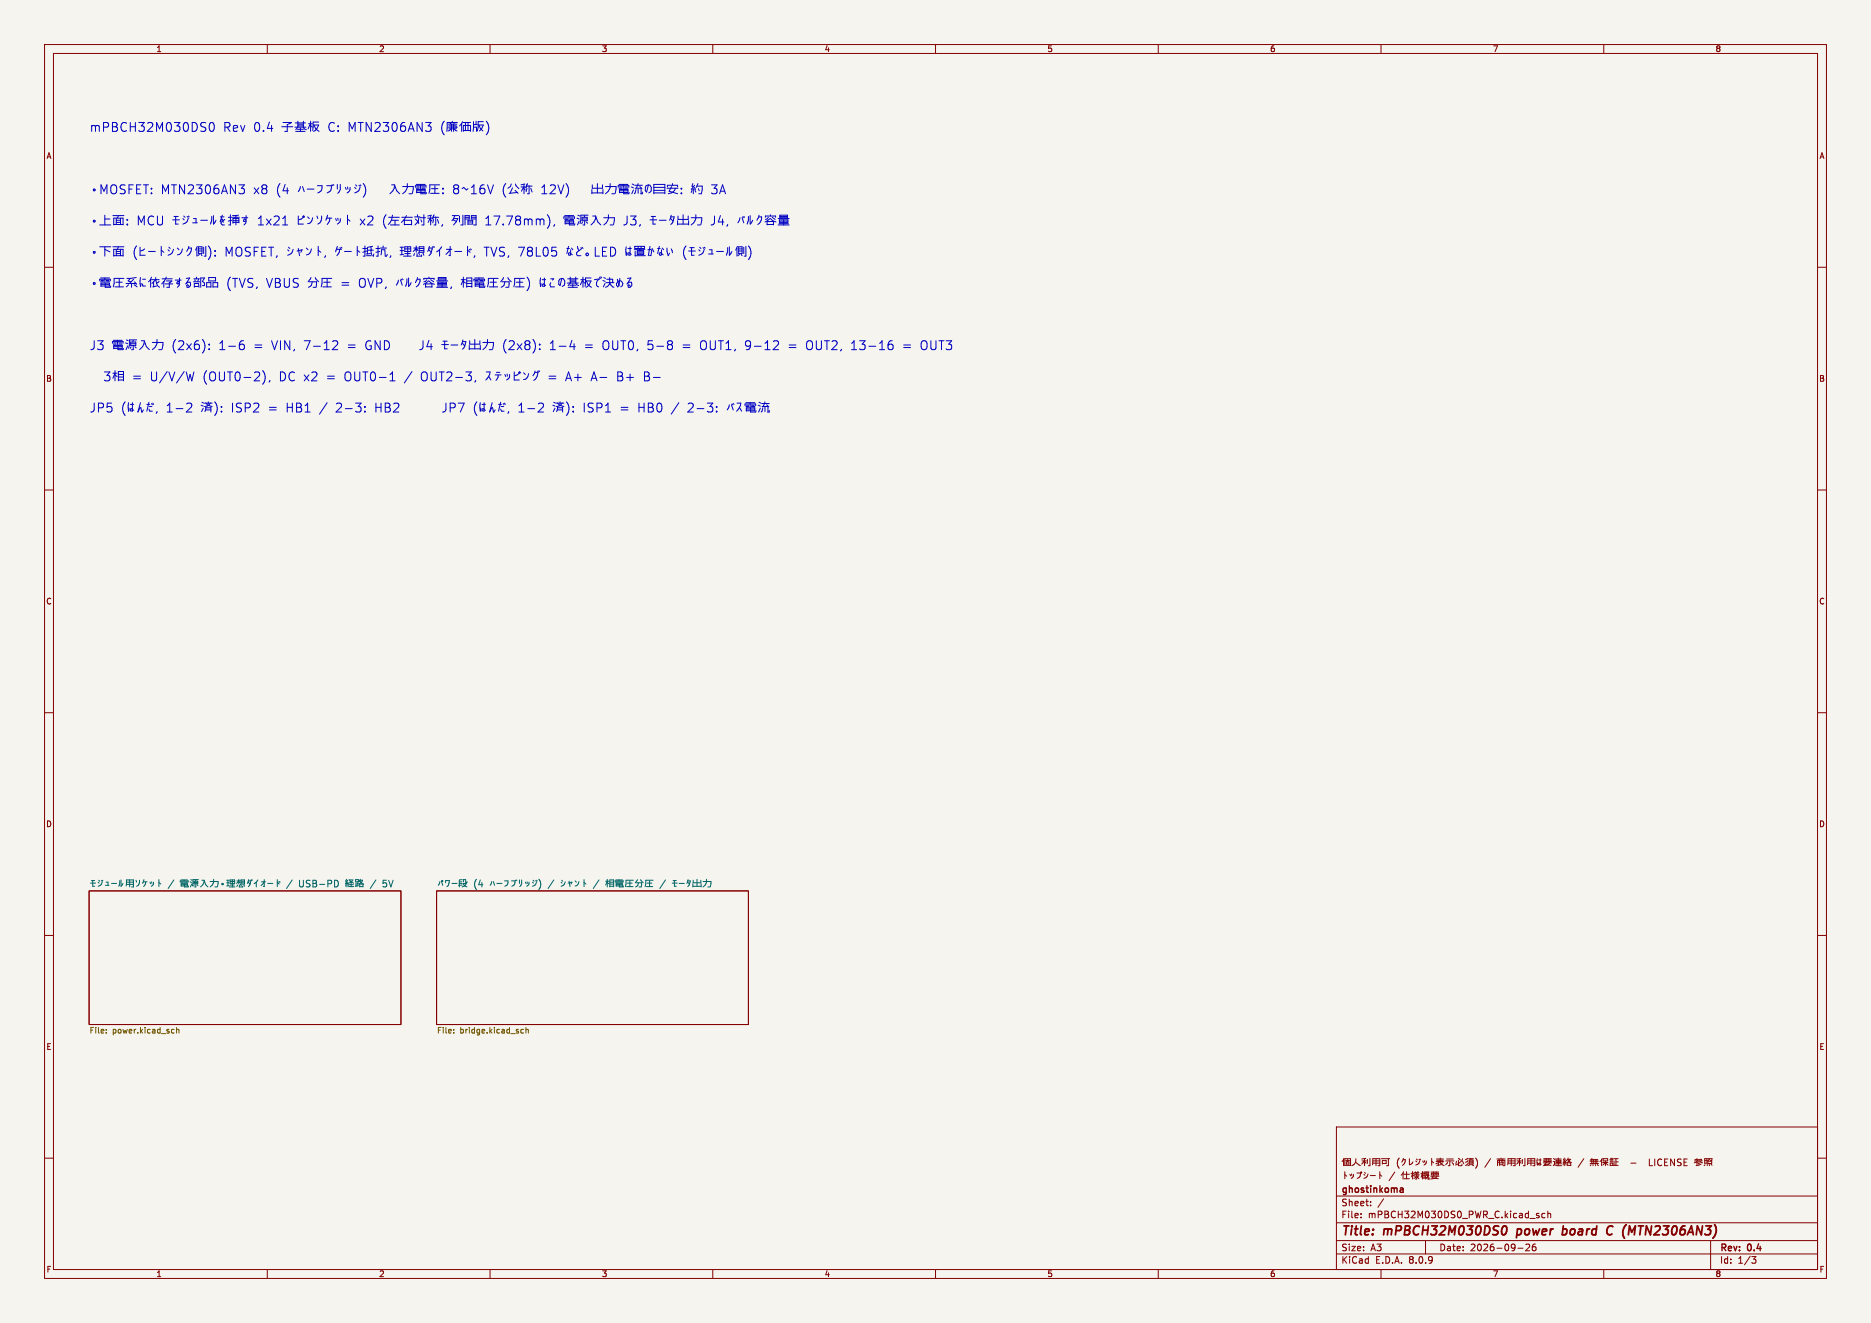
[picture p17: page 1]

þÿ0ûN—b þÿ(0Ò0ü0È0·0ó0¯Pt): MOSFET, þÿ0·0ã0ó0È, þÿ0²0ü0Èbµb—, þÿt`ó0À0¤0ª0ü0É, TVS, 78L05 þÿ0j0i0-

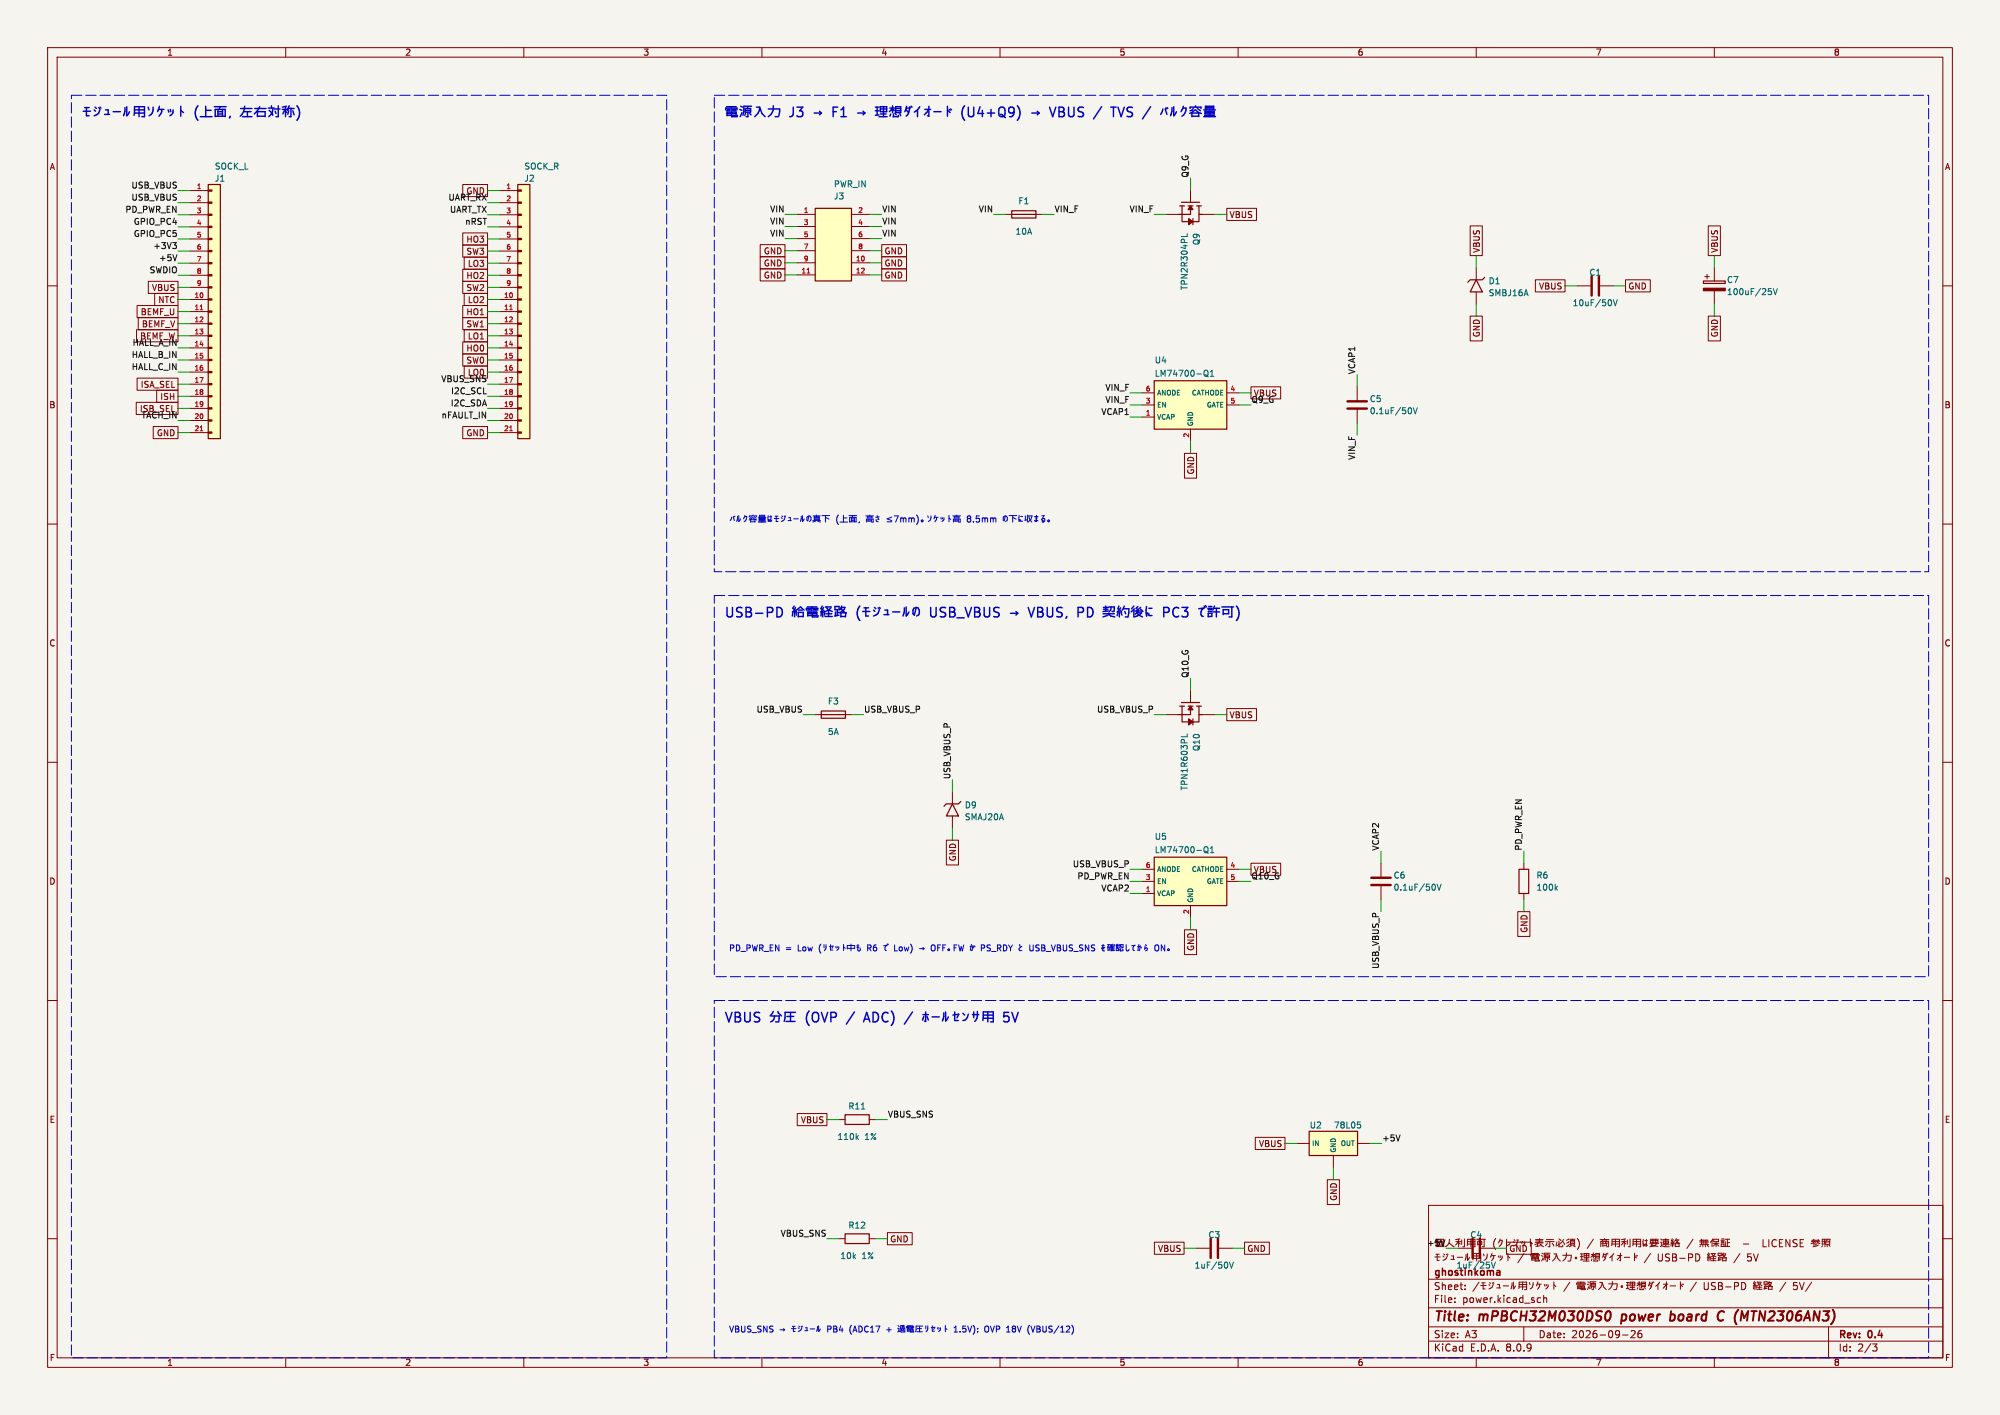
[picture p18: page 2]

2 EN 3 CATHODE 4 GATE 5 ANODE 6 U4

USB-PD þÿ}f–û}L•ï þÿ(0â0¸0å0ü0ë0n USB_VBUS þÿ!’VBUS, PD þÿYQ}_Œ0k PC3 þÿ0gŠ1Sï) PD_PWR_EN = Low þÿ(0ê0»0Ã0ÈN-0‚ R6 þÿ0gLow) þÿ!’þÿOFF0-

2 EN 3 CATHODE 4 GATE 5 ANODE 6 U5

VBUS þÿRW'(OVP / ADC) / þÿ0Û0ü0ë0»0ó0µu( 5V

VBUS_SNS þÿ!’þÿ0â0¸0å0ü0ë PB4 (ADC17 + þÿ•N–ûW'0ê0»0Ã0È 1.5V): OVP 18V (VBUS/12)

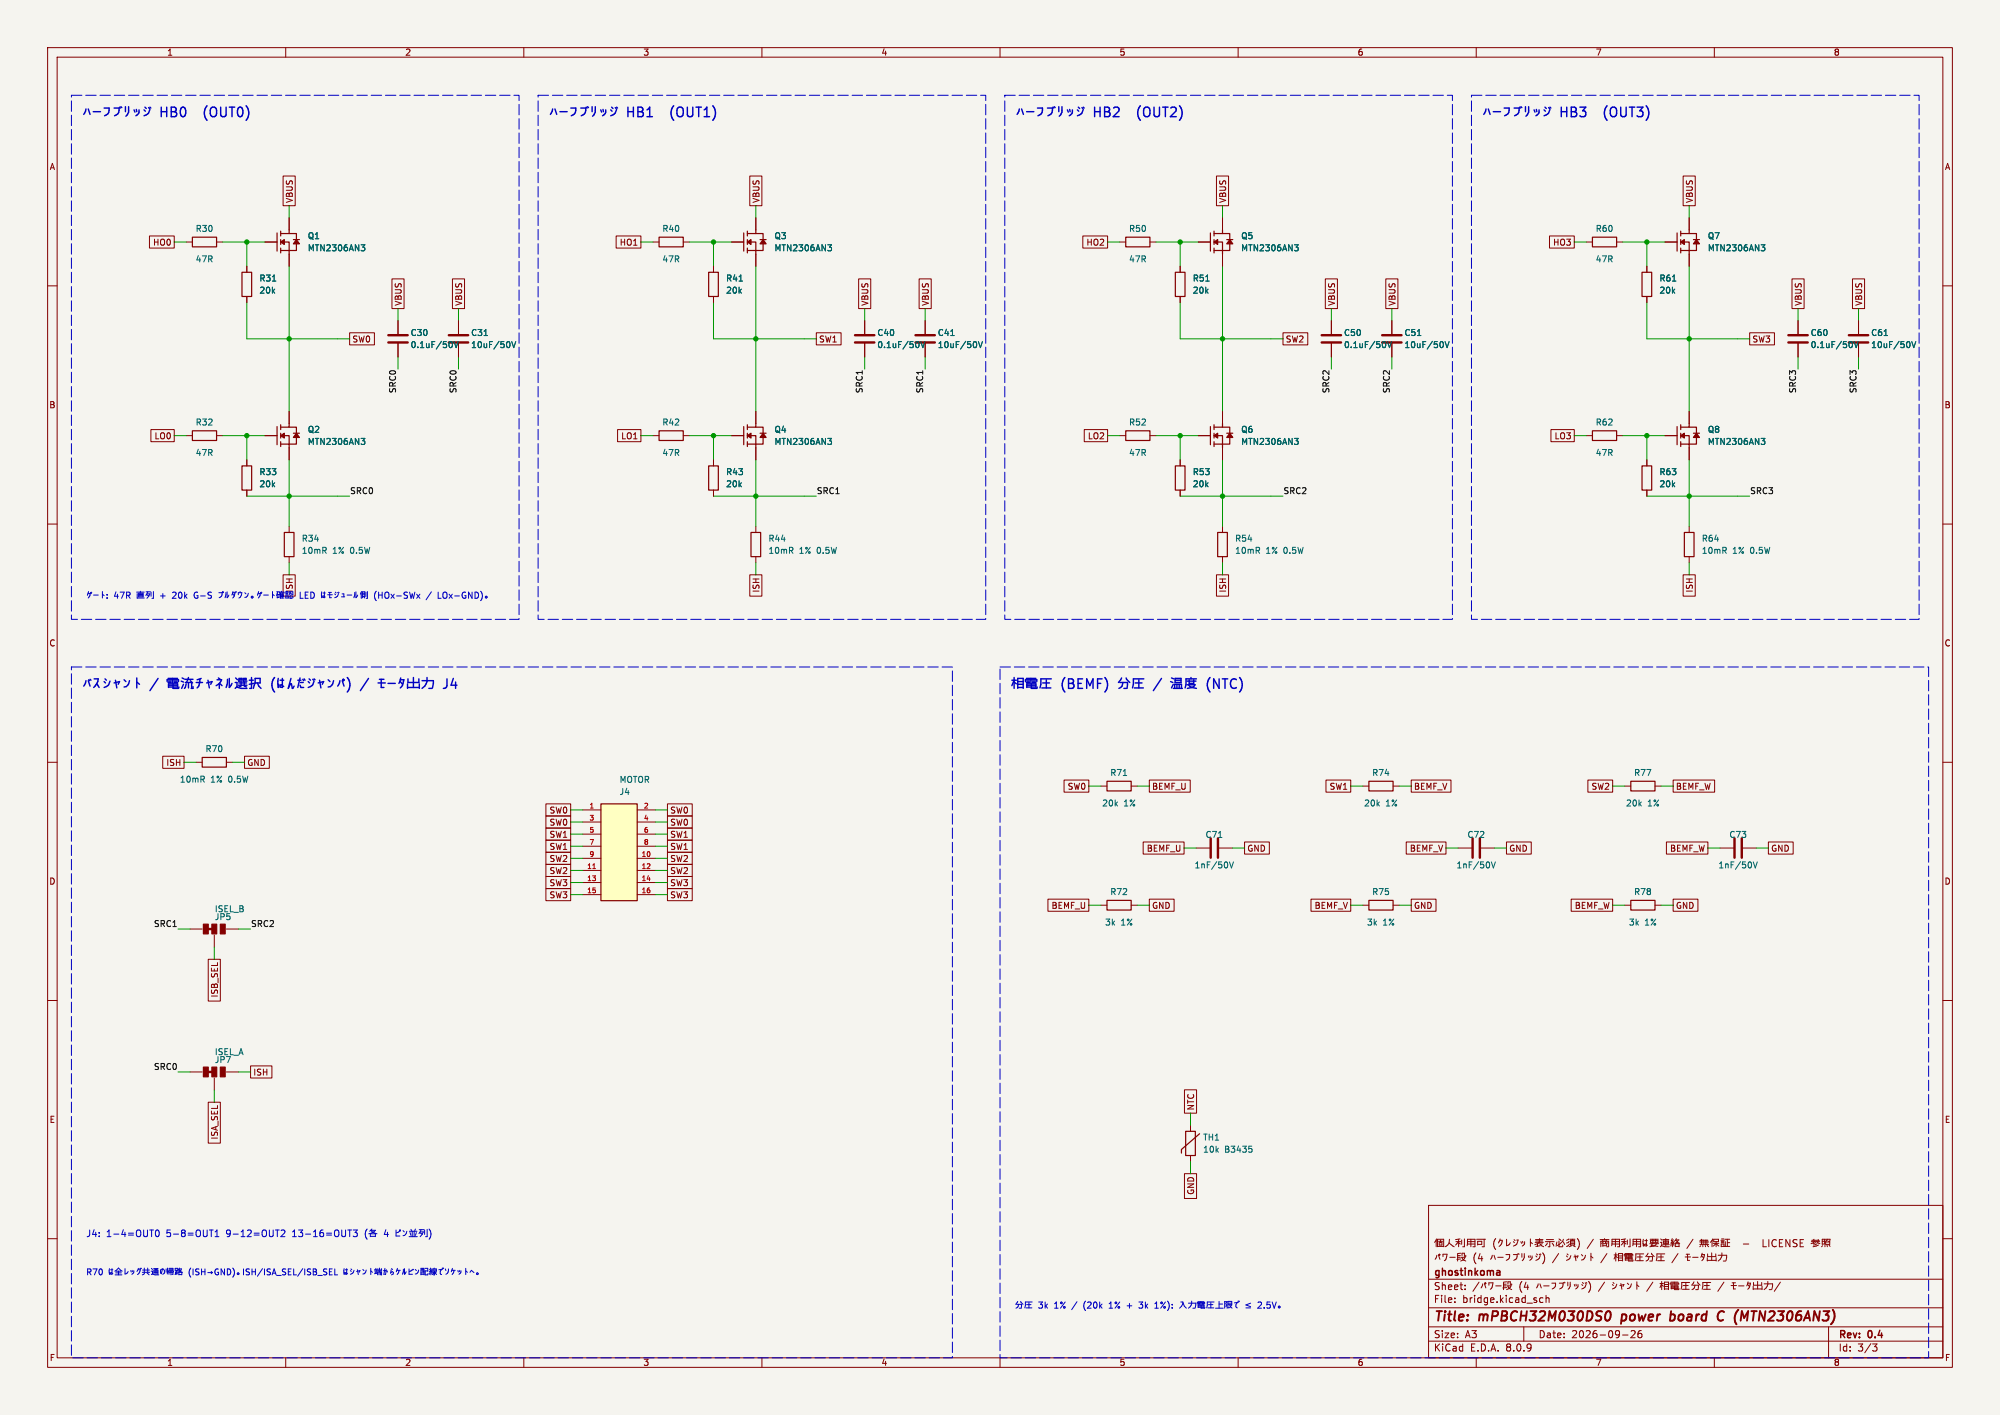
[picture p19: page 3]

0²0ü0ÈxºŠ• LED þÿ0o0â0¸0å0ü0ëPt (HOx-SWx / þÿLOx-GND)0-

þÿ0Ð0¹0·0ã0ó0È / þÿ–ûmA0Á0ã0Í0ë•xbž þÿ(0o0“0`0¸0ã0ó0Ñ) / þÿ0â0ü0¿QúR› J4

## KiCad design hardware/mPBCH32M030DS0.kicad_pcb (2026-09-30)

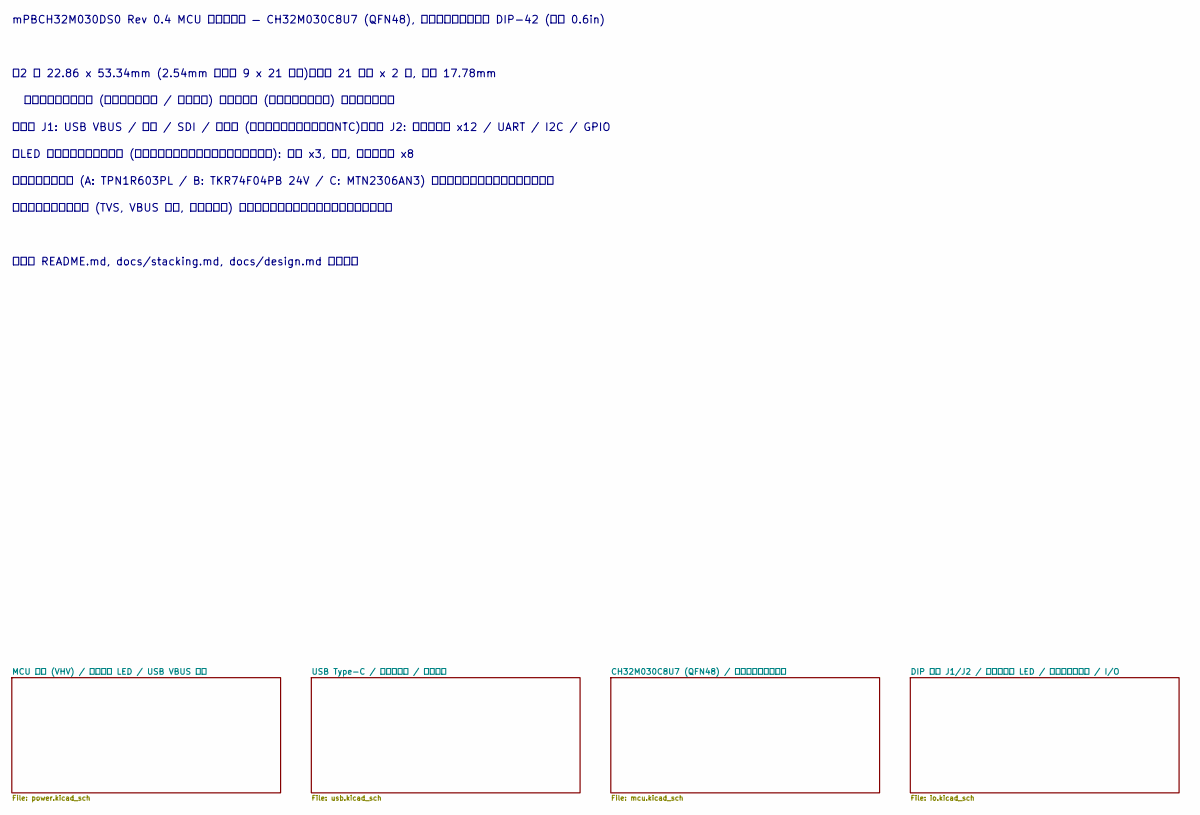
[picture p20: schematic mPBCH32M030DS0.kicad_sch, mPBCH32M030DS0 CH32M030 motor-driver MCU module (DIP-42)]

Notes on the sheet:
mPBCH32M030DS0 Rev 0.4 MCU モジュール — CH32M030C8U7 (QFN48), ブレッドボード対応 DIP-42 (列間 0.6in)
・2 層 22.86 x 53.34mm (2.54mm 格子で 9 x 21 マス)。左右 21 ピン x 2 列, 列間 17.78mm
ピンヘッダは裏から (ブレッドボード / 子基板用) でも表から (ジャンパワイヤ用) でも実装できる
・左列 J1: USB VBUS / 電源 / SDI / センサ (相電圧・ホール・電流・NTC)。右列 J2: ゲート駆動 x12 / UART / I2C / GPIO
・LED はすべてモジュール上 (子基板の部品面はヒートシンク側のため): 電源 x3, 状態, ゲート確認 x8
・パワー段子基板 (A: TPN1R603PL / B: TKR74F04PB 24V / C: MTN2306AN3) は左右対称のピンソケットで受ける
・電圧に依存する部品 (TVS, VBUS 分圧, バルク容量) は子基板側。モジュールは電圧に依存しない
詳細は README.md, docs/stacking.md, docs/design.md を参照。

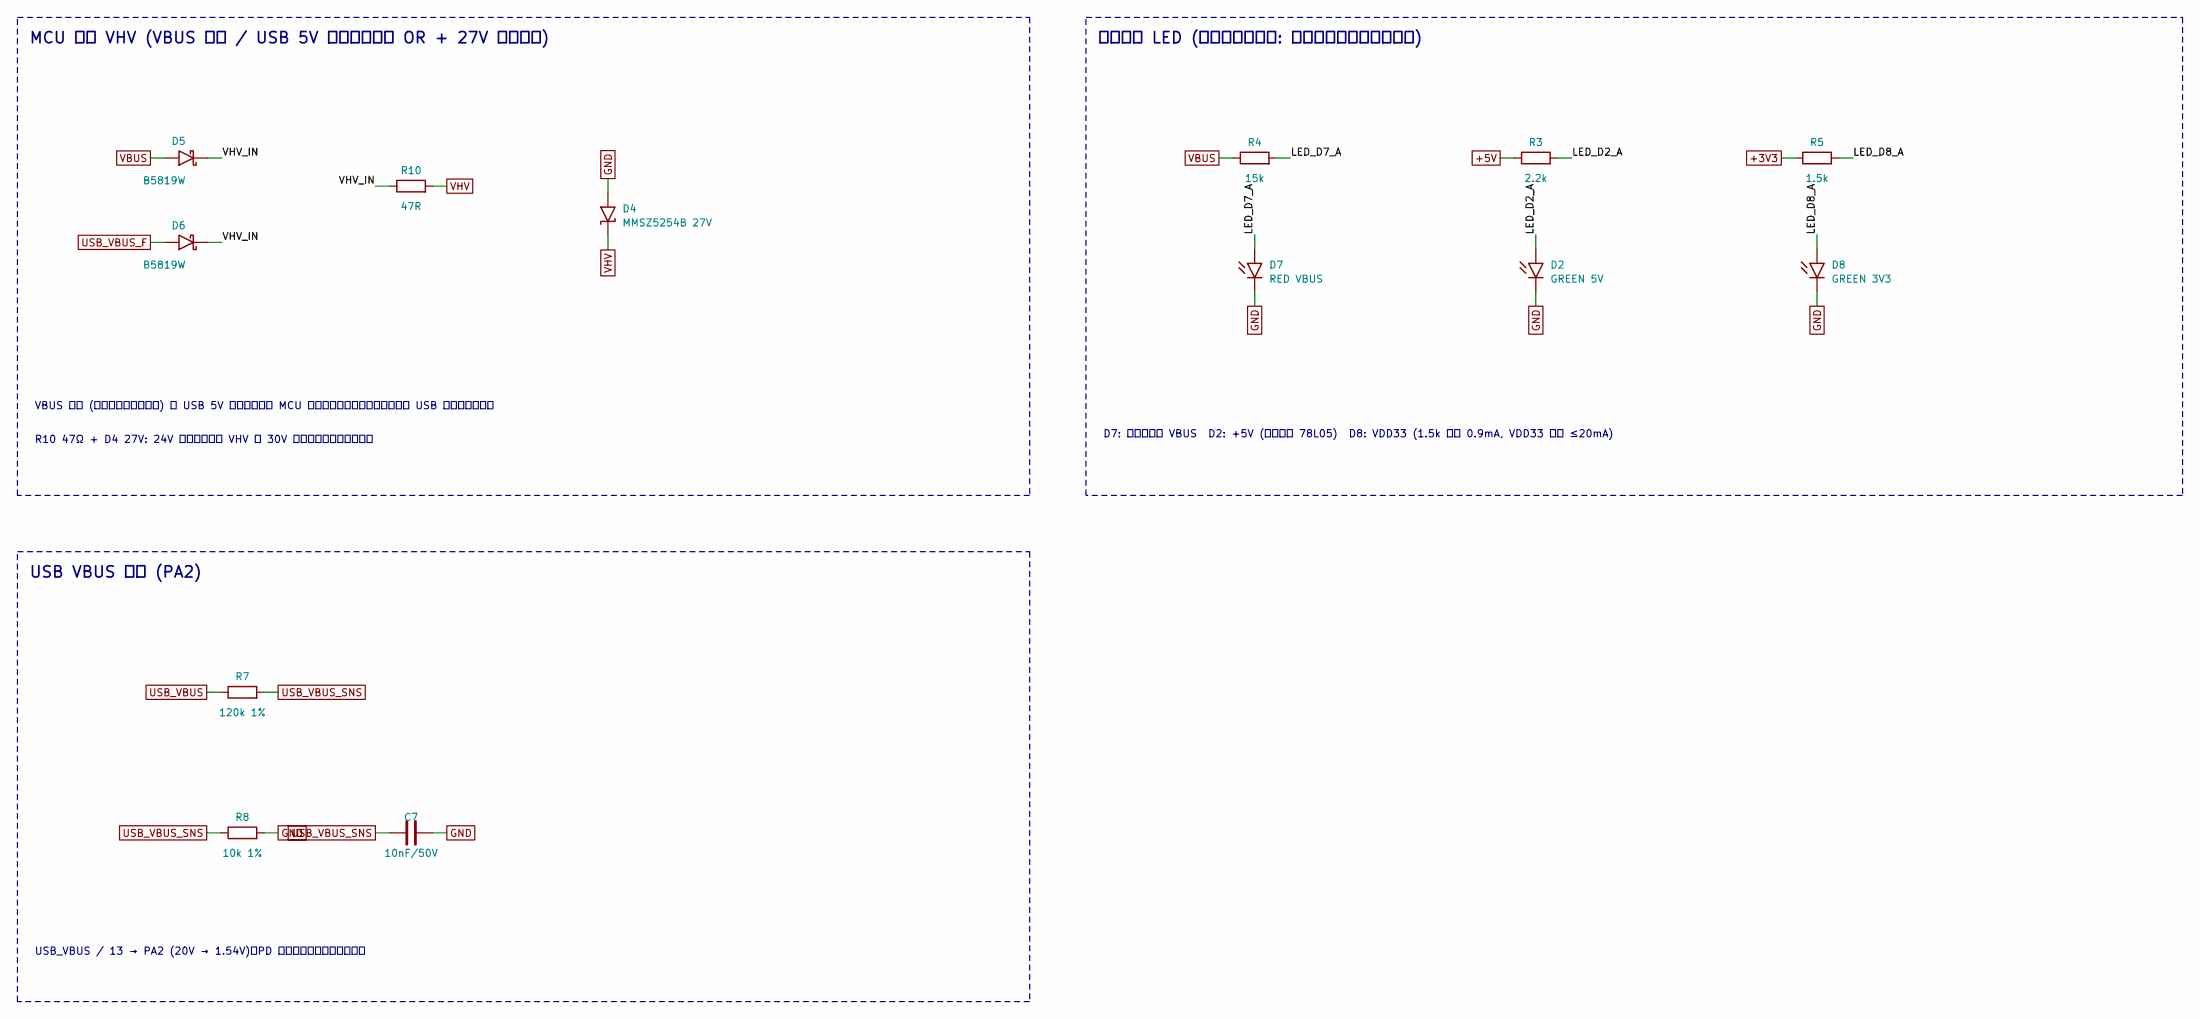
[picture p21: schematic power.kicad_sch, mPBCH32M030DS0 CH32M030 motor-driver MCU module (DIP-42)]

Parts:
C7: 10nF/50V; C_0402_1005Metric; MPN Murata GRM155R71H103KA88D (X7R 1005)
D2: GREEN 5V; LED_0603_1608Metric; MPN 1608 チップ LED
D4: MMSZ5254B 27V; D_SOD-123; MPN MMSZ5254B (27V 500mW, VHV 絶対最大 30V の保護)
D5, D6: B5819W; D_SOD-123; MPN B5819W (40V 1A ショットキー)
D7: RED VBUS; LED_0603_1608Metric; MPN 1608 チップ LED
D8: GREEN 3V3; LED_0603_1608Metric; MPN 1608 チップ LED
R3: 2.2k; R_0402_1005Metric
R4: 15k; R_0402_1005Metric
R5: 1.5k; R_0402_1005Metric
R7: 120k 1%; R_0402_1005Metric
R8: 10k 1%; R_0402_1005Metric
R10: 47R; R_0603_1608Metric

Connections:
+3V3: R5.1; also elsewhere on the board
+5V: R3.1; also elsewhere on the board
GND: C7.2, D2.1 (K), D4.2 (A), D7.1 (K), D8.1 (K), R8.2; also elsewhere on the board
LED_D2_A: D2.2 (A), R3.2
LED_D7_A: D7.2 (A), R4.2
LED_D8_A: D8.2 (A), R5.2
USB_VBUS: R7.1; also elsewhere on the board
USB_VBUS_F: D6.2 (A); also elsewhere on the board
USB_VBUS_SNS: C7.1, R7.2, R8.1; also elsewhere on the board
VBUS: D5.2 (A), R4.1; also elsewhere on the board
VHV: D4.1 (K), R10.2; also elsewhere on the board
VHV_IN: D5.1 (K), D6.1 (K), R10.1

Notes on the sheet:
MCU 電源 VHV (VBUS ピン / USB 5V のダイオード OR + 27V クランプ)
電源表示 LED (モジュール上面: 子基板を付けても見える)
USB VBUS 監視 (PA2)
VBUS ピン (子基板のモータ電源) か USB 5V のどちらかで MCU が動く。ブレッドボード単体は USB 給電のみで可。
R10 47Ω + D4 27V: 24V 系のサージで VHV が 30V を超えないようにする。
D7: モータ電源 VBUS D2: +5V (子基板の 78L05) D8: VDD33 (1.5k で約 0.9mA, VDD33 負荷 ≤20mA)
USB_VBUS / 13 → PA2 (20V → 1.54V)。PD 契約後の電圧確認に使う。

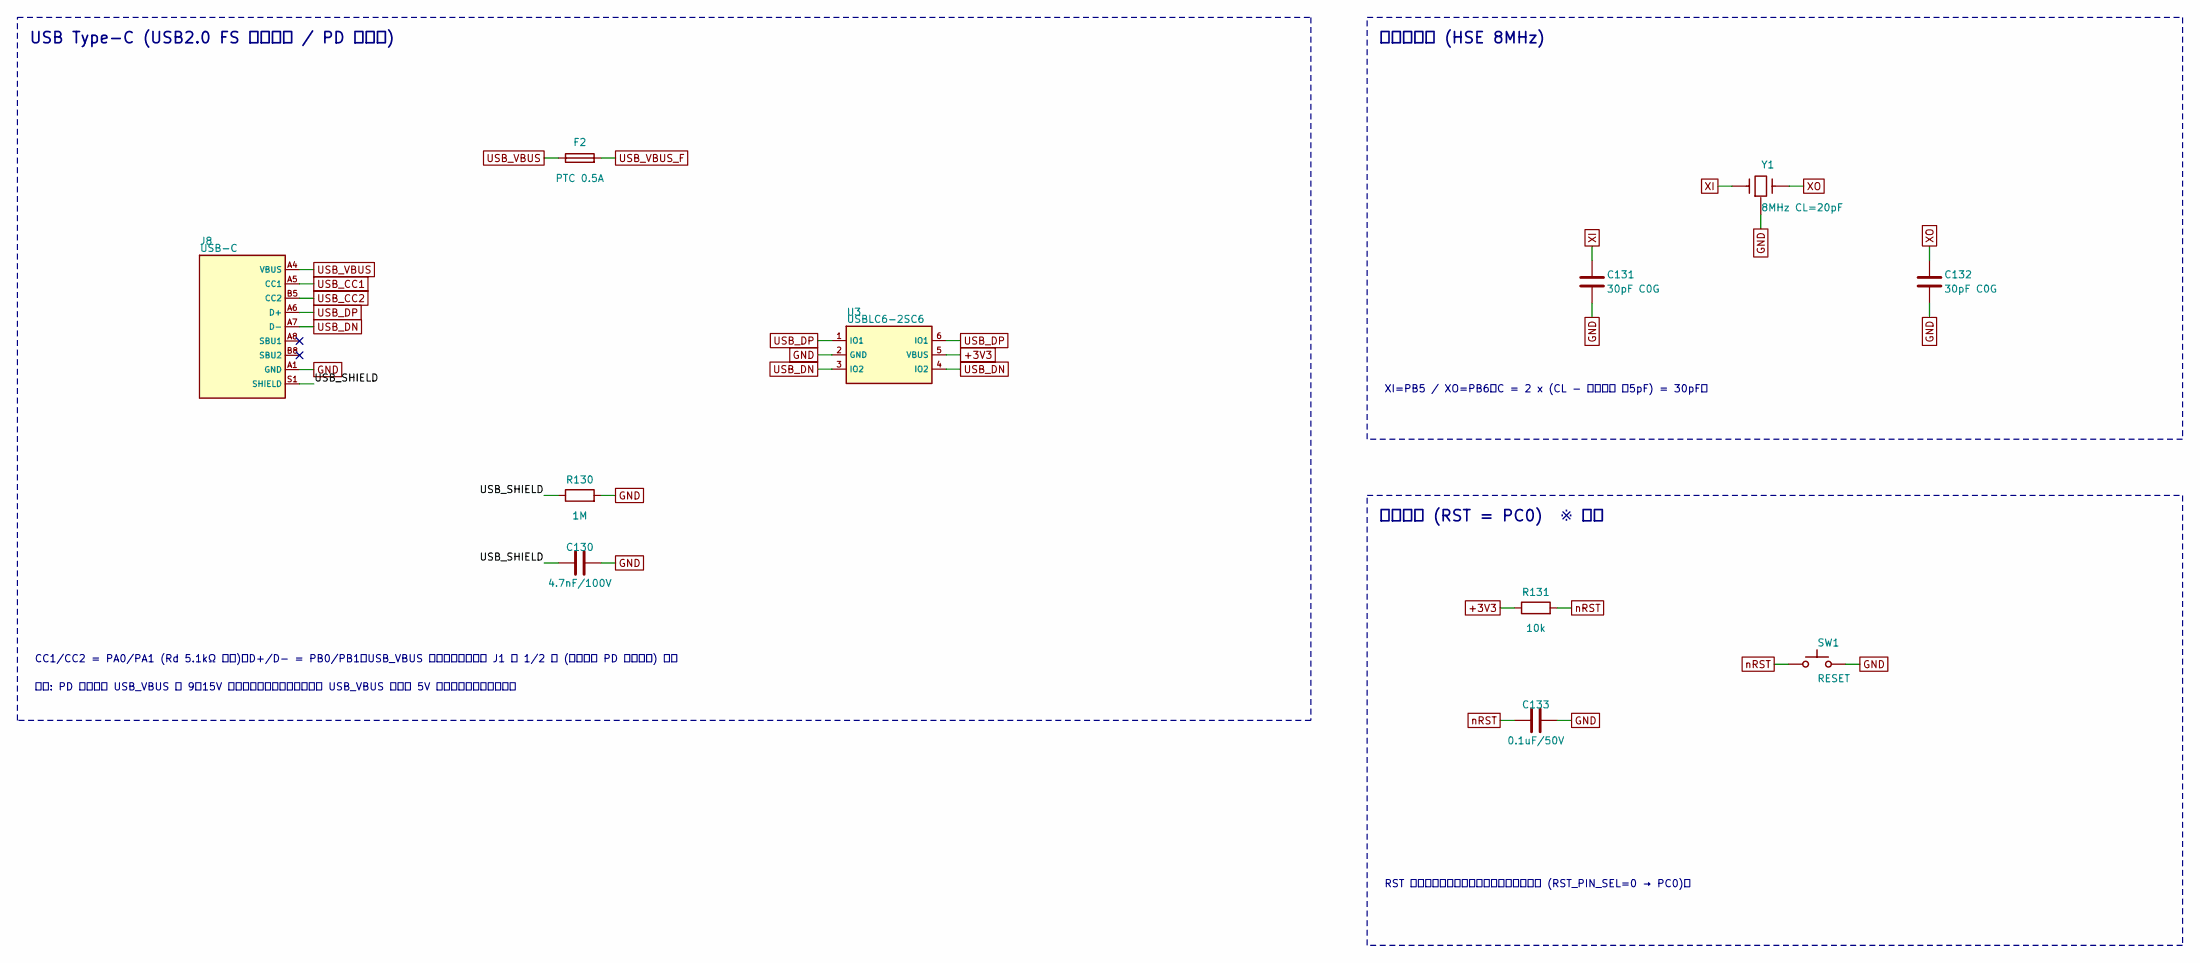
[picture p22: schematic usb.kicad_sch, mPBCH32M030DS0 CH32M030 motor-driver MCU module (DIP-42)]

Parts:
C130: 4.7nF/100V; C_0603_1608Metric; MPN Samsung CL10B472KC8NNNC (X7R 100V 1608)
C131, C132: 30pF C0G; C_0402_1005Metric; MPN Murata GRM1555C1H300JA01D (C0G 1005)
C133: 0.1uF/50V; C_0402_1005Metric; MPN Murata GRM155R71H104KE14D (X7R 1005)
F2: PTC 0.5A; Fuse_1206_3216Metric; MPN ポリスイッチ 0.5A 1206 (例: Bourns MF-NSMF050)
J8: USB-C; USB_C_Receptacle_GCT_USB4105-xx-A_16P_TopMnt_Horizontal; MPN GCT USB4105-GF-A (USB-C 16P)
R130: 1M; R_0402_1005Metric
R131: 10k; R_0402_1005Metric
SW1: RESET; SW_SPST_B3U-1000P; MPN Omron B3U-1000P (3x2.5mm SMD タクト, 上押し)
U3: USBLC6-2SC6; SOT-23-6; MPN ST USBLC6-2SC6 (D+/D- ESD 保護, 基準は +3V3)
Y1: 8MHz CL=20pF; Crystal_SMD_3225-4Pin_3.2x2.5mm; MPN 8MHz 3225 4pad, CL=20pF, ESR≤60Ω (例: Ab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

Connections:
+3V3: R131.1, U3.5 (VBUS); also elsewhere on the board
GND: C130.2, C131.2, C132.2, C133.2, J8.A1 (GND), J8.A12 (GND), J8.B1 (GND), J8.B12 (GND), R130.2, SW1.2, U3.2 (GND), Y1.2 (GND), Y1.4 (GND); also elsewhere on the board
USB_CC1: J8.A5 (CC1); also elsewhere on the board
USB_CC2: J8.B5 (CC2); also elsewhere on the board
USB_DN: J8.A7 (D-), J8.B7 (D-), U3.3 (IO2), U3.4 (IO2); also elsewhere on the board
USB_DP: J8.A6 (D+), J8.B6 (D+), U3.1 (IO1), U3.6 (IO1); also elsewhere on the board
USB_SHIELD: C130.1, J8.S1 (SHIELD), R130.1
USB_VBUS: F2.1, J8.A4 (VBUS), J8.A9 (VBUS), J8.B4 (VBUS), J8.B9 (VBUS); also elsewhere on the board
USB_VBUS_F: F2.2; also elsewhere on the board
XI: C131.1, Y1.1; also elsewhere on the board
XO: C132.1, Y1.3; also elsewhere on the board
nRST: C133.1, R131.2, SW1.1; also elsewhere on the board

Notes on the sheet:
USB Type-C (USB2.0 FS デバイス / PD シンク)
水晶発振子 (HSE 8MHz)
リセット (RST = PC0) ※ 上面
CC1/CC2 = PA0/PA1 (Rd 5.1kΩ 内蔵)。D+/D- = PB0/PB1。USB_VBUS はモジュール端子 J1 の 1/2 番 (子基板の PD 給電経路) へ。
注意: PD 契約後は USB_VBUS が 9〜15V になる。ブレッドボードでは USB_VBUS ピンに 5V 部品を直結しないこと。
XI=PB5 / XO=PB6。C = 2 x (CL - 浮遊容量 約5pF) = 30pF。
RST ピンはユーザオプションバイトで有効化 (RST_PIN_SEL=0 → PC0)。

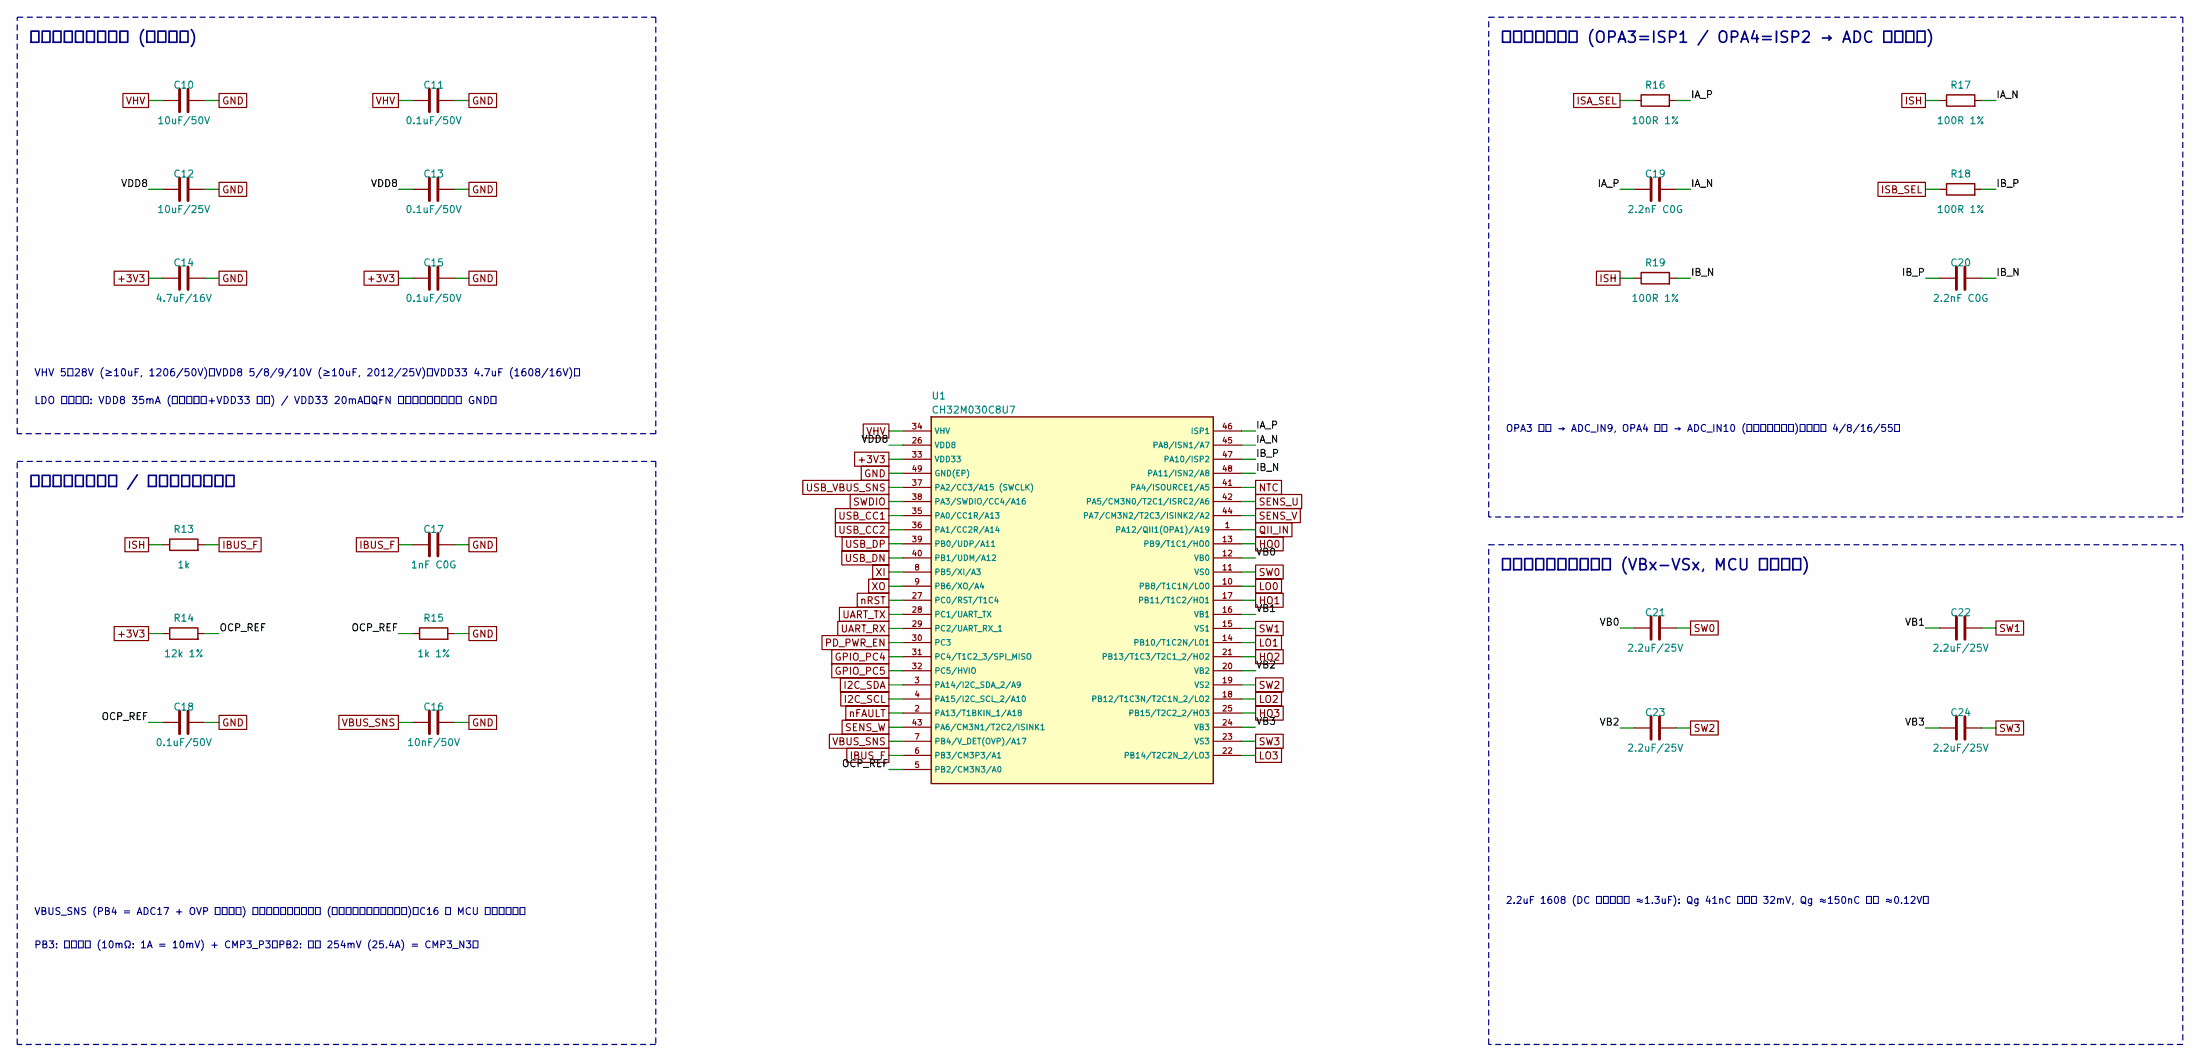
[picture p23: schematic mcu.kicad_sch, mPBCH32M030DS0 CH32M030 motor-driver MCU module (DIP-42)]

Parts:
C10: 10uF/50V; C_1206_3216Metric; MPN Murata GRM31CR61H106KA12L (X5R 1206)
C11, C13, C15, C18: 0.1uF/50V; C_0402_1005Metric; MPN Murata GRM155R71H104KE14D (X7R 1005)
C12: 10uF/25V; C_0805_2012Metric; MPN Murata GRM21BR61E106KA73L (X5R 2012)
C14: 4.7uF/16V; C_0603_1608Metric; MPN Samsung CL10A475KO8NNNC (X5R 1608)
C16: 10nF/50V; C_0402_1005Metric; MPN Murata GRM155R71H103KA88D (X7R 1005)
C17: 1nF C0G; C_0402_1005Metric; MPN Murata GRM1555C1H102JA01D (C0G 1005)
C19, C20: 2.2nF C0G; C_0402_1005Metric; MPN Murata GRM1555C1H222JA01D (C0G 1005)
C21, C22, C23, C24: 2.2uF/25V; C_0603_1608Metric; MPN Murata GRM188R61E225KA12D (X5R 1608)
R13: 1k; R_0402_1005Metric
R14: 12k 1%; R_0402_1005Metric
R15: 1k 1%; R_0402_1005Metric
R16, R17, R18, R19: 100R 1%; R_0402_1005Metric
U1: CH32M030C8U7; CH32M030DS0_QFN48; MPN WCH CH32M030C8U7 (QFN48 5x5mm 0.35mm pi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

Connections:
+3V3: C14.1, C15.1, R14.1, U1.33 (PC4); also elsewhere on the board
GND: C10.2, C11.2, C12.2, C13.2, C14.2, C15.2, C16.2, C17.2, C18.2, R15.2, U1.0 (GND), U1.49 (GND(EP)); also elsewhere on the board
GPIO_PC4: U1.31 (PC1/T3C2); also elsewhere on the board
GPIO_PC5: U1.32 (PC3); also elsewhere on the board
HO0: U1.13 (VS0); also elsewhere on the board
HO1: U1.17 (VS1); also elsewhere on the board
HO2: U1.21 (VS2); also elsewhere on the board
HO3: U1.25 (VS3); also elsewhere on the board
I2C_SCL: U1.4 (PA13/QII2/A18); also elsewhere on the board
I2C_SDA: U1.3 (PA12/QII1/A19); also elsewhere on the board
IA_N: C19.2, R17.2, U1.45 (PA6/ISINK1/CM3N1)
IA_P: C19.1, R16.2, U1.46 (PA7/ISINK2/CM3N2/A2)
IBUS_F: C17.1, R13.2, U1.6 (PA15/T1BK/Q_DET2/A10); also elsewhere on the board
IB_N: C20.2, R19.2, U1.48 (ISP1)
IB_P: C20.1, R18.2, U1.47 (PA8/ISN1/CM3O/A7)
ISA_SEL: R16.1; also elsewhere on the board
ISB_SEL: R18.1; also elsewhere on the board
ISH: R13.1, R17.1, R19.1; also elsewhere on the board
LO0: U1.10 (PB5/XI/CM2P/A3); also elsewhere on the board
LO1: U1.14 (VB0); also elsewhere on the board
LO2: U1.18 (VB1); also elsewhere on the board
LO3: U1.22 (VB2); also elsewhere on the board
NTC: U1.41 (PB0/UDP/T2C2_/CM3P1/A11); also elsewhere on the board
OCP_REF: C18.1, R14.2, R15.1, U1.5 (PA14/Q_DET1/A9)
PD_PWR_EN: U1.30 (PC0/T1C4/T3C1); also elsewhere on the board
QII_IN: U1.1 (PA10/ISP2); also elsewhere on the board
SENS_U: U1.42 (PB1/UDM/T2C3_/CM3P2/A12); also elsewhere on the board
SENS_V: U1.44 (PA5/ISRC2/CM3N0/A6); also elsewhere on the board
SENS_W: U1.43 (PA4/ISRC1/A5); also elsewhere on the board
SW0: C21.2, U1.11 (PB6/XO/CM2N/A4); also elsewhere on the board
SW1: C22.2, U1.15 (PB9/T1C1/HO0); also elsewhere on the board
SW2: C23.2, U1.19 (PB11/T1C2/HO1); also elsewhere on the board
SW3: C24.2, U1.23 (PB13/T1C3/T2C1/HO2); also elsewhere on the board
SWDIO: U1.38 (PA1/CC2R/A14); also elsewhere on the board
UART_RX: U1.29 (PB7); also elsewhere on the board
UART_TX: U1.28 (VDD8); also elsewhere on the board
USB_CC1: U1.35 (VDD33); also elsewhere on the board
USB_CC2: U1.36 (VHV); also elsewhere on the board
USB_DN: U1.40 (PA3/SWIO/CC4/T2C1_/SDA_/CM3P0/A16); also elsewhere on the board
USB_DP: U1.39 (PA2/SWCK/CC3/SCL_/A15); also elsewhere on the board
USB_VBUS_SNS: U1.37 (PA0/CC1R/A13); also elsewhere on the board
VB0: C21.1, U1.12 (PB8/T1C1N/LO0)
VB1: C22.1, U1.16 (PB10/T1C2N/LO1)
VB2: C23.1, U1.20 (PB12/T1C3N/T2C1N/LO2)
VB3: C24.1, U1.24 (PB14/T3C2N/T2C2N/LO3)
VBUS_SNS: C16.1, U1.7 (PB2/T2C4_/SDA/CM3N3/A0); also elsewhere on the board
VDD8: C12.1, C13.1, U1.26 (VB3)
VHV: C10.1, C11.1, U1.34 (PC5/HVIO); also elsewhere on the board
XI: U1.8 (PB3/SCL/CM3P3/A1); also elsewhere on the board
XO: U1.9 (PB4/V_DET/A17); also elsewhere on the board
nFAULT: U1.2 (PA11/ISN2/A8); also elsewhere on the board
nRST: U1.27 (PB15/T3C2/T2C2/HO3); also elsewhere on the board

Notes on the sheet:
電源デカップリング (ピン直近)
バス電流フィルタ / 過電流比較の閾値
電流アンプ入力 (OPA3=ISP1 / OPA4=ISP2 → ADC 内部接続)
ブートストラップ容量 (VBx-VSx, MCU ピン直近)
VHV 5〜28V (≥10uF, 1206/50V)。VDD8 5/8/9/10V (≥10uF, 2012/25V)。VDD33 4.7uF (1608/16V)。
LDO 負荷上限: VDD8 35mA (ゲート駆動+VDD33 含む) / VDD33 20mA。QFN 裏面パッドが唯一の GND。
VBUS_SNS (PB4 = ADC17 + OVP リセット) の分圧抵抗は子基板側 (電圧系ごとに定数が違う)。C16 は MCU 直近の平滑。
PB3: バス電流 (10mΩ: 1A = 10mV) + CMP3_P3。PB2: 閾値 254mV (25.4A) = CMP3_N3。
OPA3 出力 → ADC_IN9, OPA4 出力 → ADC_IN10 (チップ内部接続)。ゲイン 4/8/16/55。
2.2uF 1608 (DC バイアス後 ≈1.3uF): Qg 41nC で降下 32mV, Qg ≈150nC でも ≈0.12V。

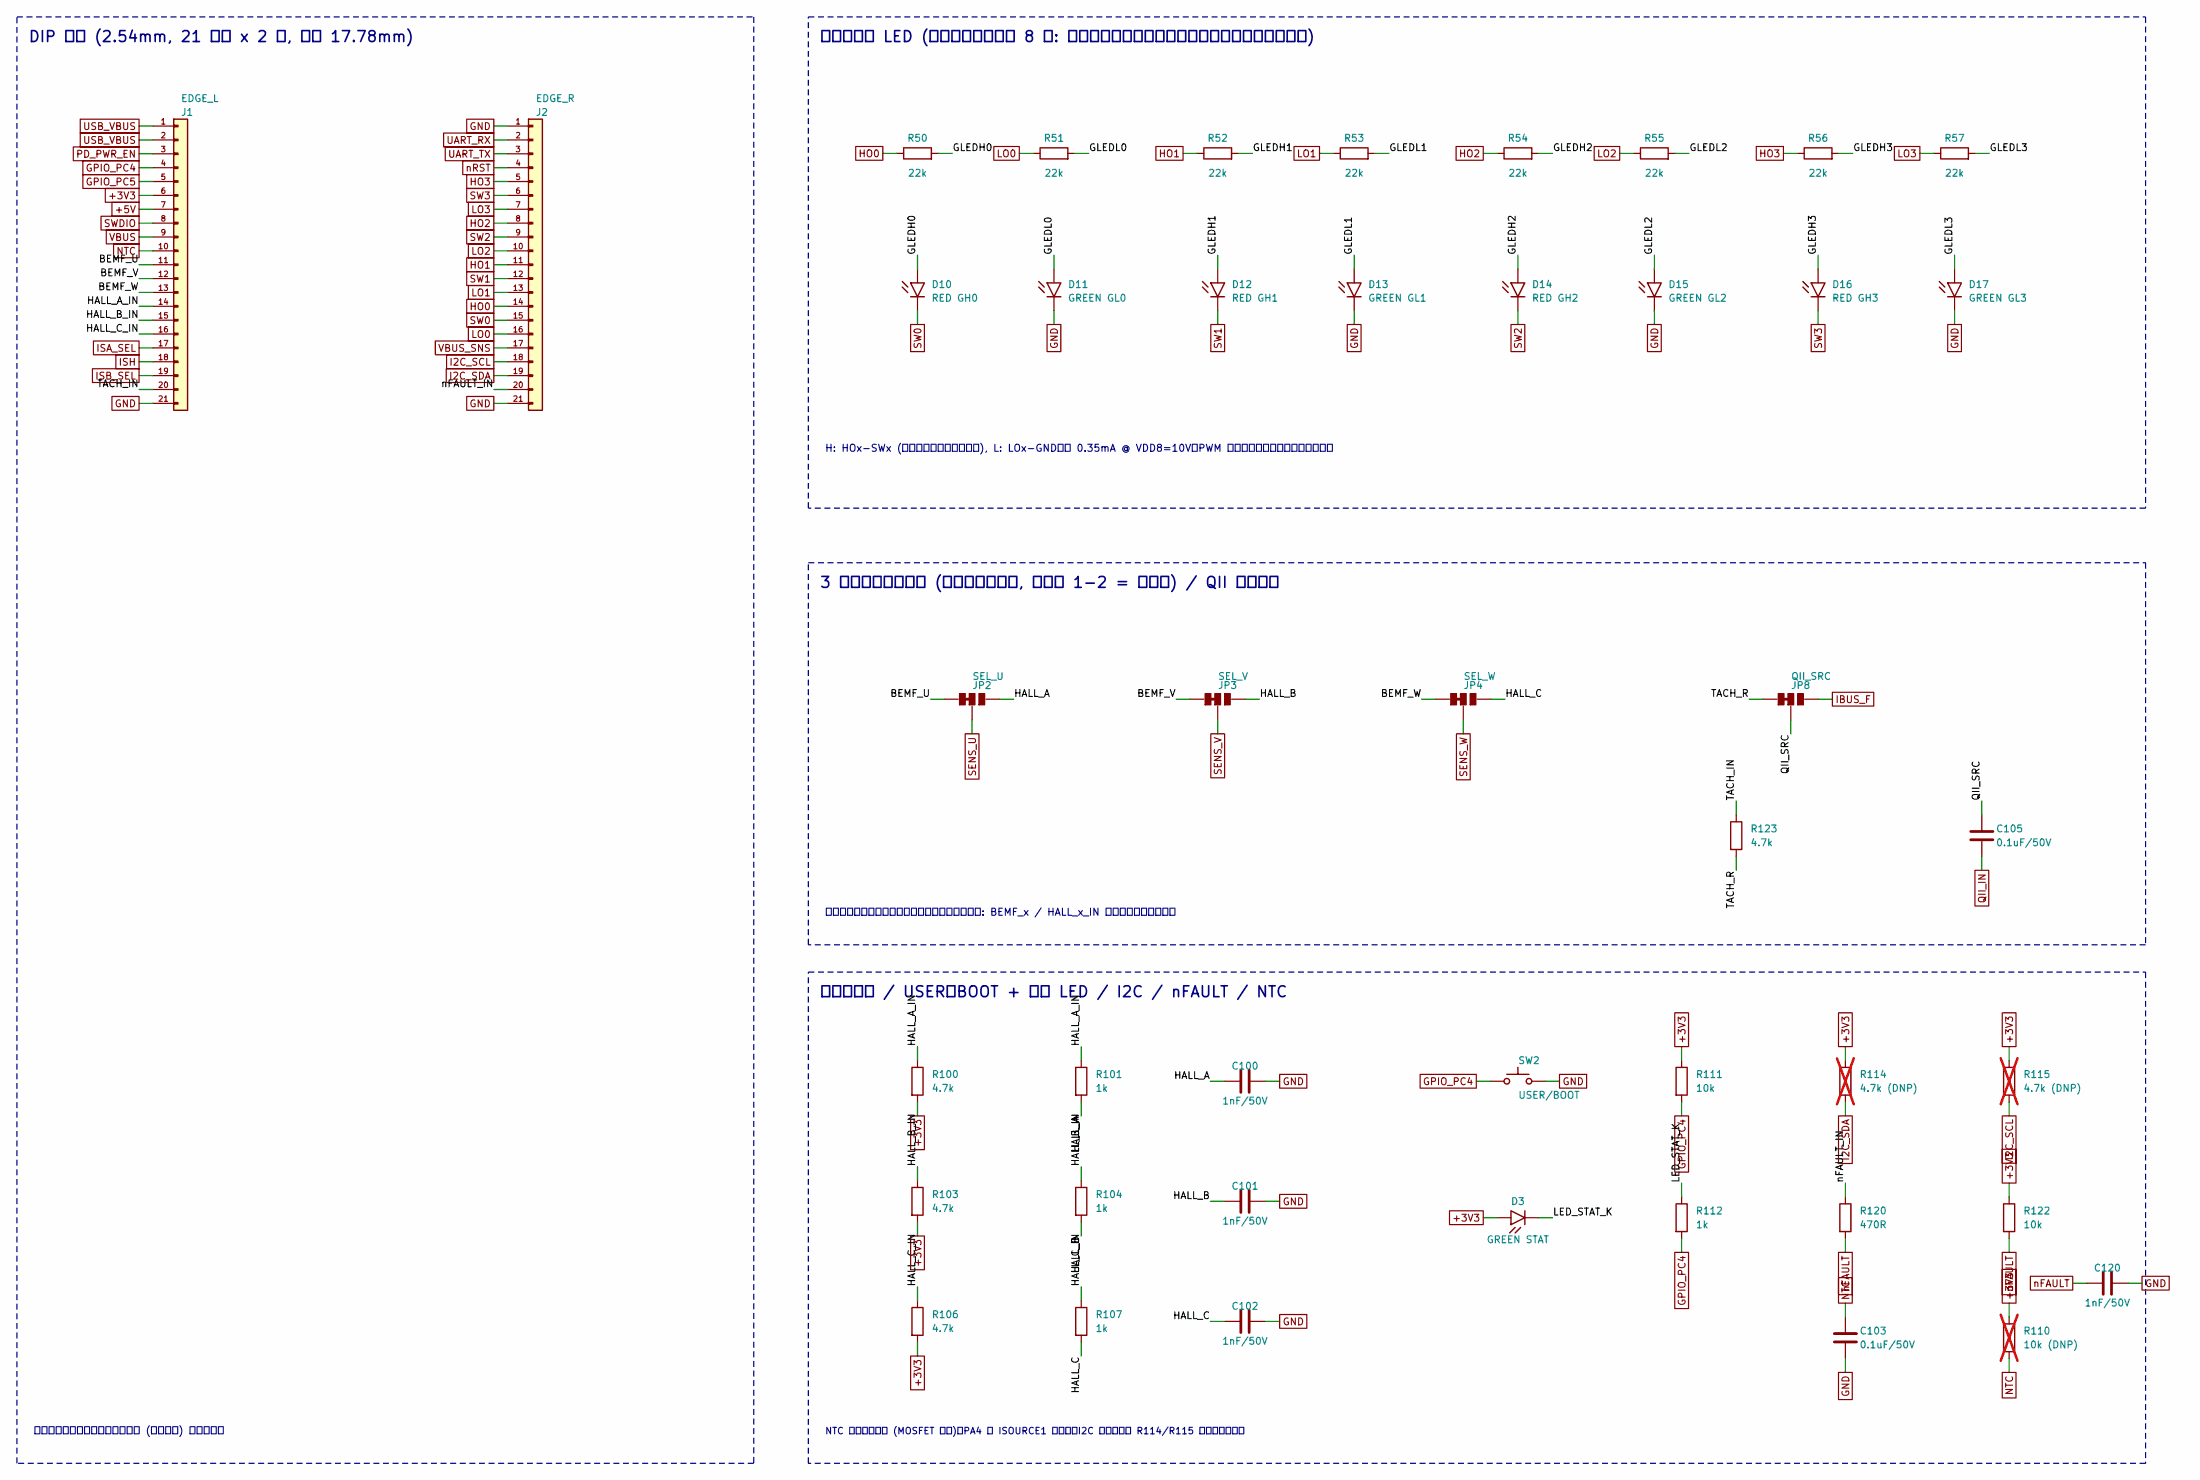
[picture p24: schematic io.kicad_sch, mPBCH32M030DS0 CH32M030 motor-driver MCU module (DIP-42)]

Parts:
C100, C101, C102, C120: 1nF/50V; C_0402_1005Metric; MPN Murata GRM155R71H102KA01D (X7R 1005)
C103, C105: 0.1uF/50V; C_0402_1005Metric; MPN Murata GRM155R71H104KE14D (X7R 1005)
D3: GREEN STAT; LED_0603_1608Metric; MPN 1608 チップ LED
D10: RED GH0; LED_0402_1005Metric; MPN 1005 チップ LED (例: Kingbright APHHS1005)
D11: GREEN GL0; LED_0402_1005Metric; MPN 1005 チップ LED (例: Kingbright APHHS1005)
D12: RED GH1; LED_0402_1005Metric; MPN 1005 チップ LED (例: Kingbright APHHS1005)
D13: GREEN GL1; LED_0402_1005Metric; MPN 1005 チップ LED (例: Kingbright APHHS1005)
D14: RED GH2; LED_0402_1005Metric; MPN 1005 チップ LED (例: Kingbright APHHS1005)
D15: GREEN GL2; LED_0402_1005Metric; MPN 1005 チップ LED (例: Kingbright APHHS1005)
D16: RED GH3; LED_0402_1005Metric; MPN 1005 チップ LED (例: Kingbright APHHS1005)
D17: GREEN GL3; LED_0402_1005Metric; MPN 1005 チップ LED (例: Kingbright APHHS1005)
J1: EDGE_L; PinHeader_1x21_P2.54mm_Vertical; MPN 2.54mm 1x21 ピンヘッダ (裏 or 表から実装)
J2: EDGE_R; PinHeader_1x21_P2.54mm_Vertical; MPN 2.54mm 1x21 ピンヘッダ (裏 or 表から実装)
JP2: SEL_U; SolderJumper-3_P1.3mm_Bridged12_RoundedPad1.0x1.5mm_NumberL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; MPN はんだジャンパ 3 端子 (1-2 ブリッジ済み: 相電圧 / 2-3: ホー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
JP3: SEL_V; SolderJumper-3_P1.3mm_Bridged12_RoundedPad1.0x1.5mm_NumberL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; MPN はんだジャンパ 3 端子 (1-2 ブリッジ済み: 相電圧 / 2-3: ホー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
JP4: SEL_W; SolderJumper-3_P1.3mm_Bridged12_RoundedPad1.0x1.5mm_NumberL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; MPN はんだジャンパ 3 端子 (1-2 ブリッジ済み: 相電圧 / 2-3: ホー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
JP8: QII_SRC; SolderJumper-3_P1.3mm_Bridged12_RoundedPad1.0x1.5mm_NumberL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; MPN はんだジャンパ 3 端子 (1-2 ブリッジ済み: TACH_IN / 2-3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
R50, R51, R52, R53, R54, R55, R56, R57: 22k; R_0402_1005Metric
R100, R103, R106, R123: 4.7k; R_0402_1005Metric
R101, R104, R107, R112: 1k; R_0402_1005Metric
R110: 10k (DNP); R_0402_1005Metric; not fitted
R111, R122: 10k; R_0402_1005Metric
R114, R115: 4.7k (DNP); R_0402_1005Metric; not fitted
R120: 470R; R_0402_1005Metric
SW2: USER/BOOT; SW_SPST_B3U-1000P; MPN Omron B3U-1000P (3x2.5mm SMD タクト, 上押し)

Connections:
+3V3: D3.2 (A), J1.6, R100.2, R103.2, R106.2, R110.1, R111.1, R114.1, R115.1, R122.1; also elsewhere on the board
+5V: J1.7; also elsewhere on the board
BEMF_U: J1.11, JP2.1
BEMF_V: J1.12, JP3.1
BEMF_W: J1.13, JP4.1
GLEDH0: D10.2 (A), R50.2
GLEDH1: D12.2 (A), R52.2
GLEDH2: D14.2 (A), R54.2
GLEDH3: D16.2 (A), R56.2
GLEDL0: D11.2 (A), R51.2
GLEDL1: D13.2 (A), R53.2
GLEDL2: D15.2 (A), R55.2
GLEDL3: D17.2 (A), R57.2
GND: C100.2, C101.2, C102.2, C103.2, C120.2, D11.1 (K), D13.1 (K), D15.1 (K), D17.1 (K), J1.21, J2.1, J2.21, SW2.2; also elsewhere on the board
GPIO_PC4: J1.4, R111.2, R112.2, SW2.1; also elsewhere on the board
GPIO_PC5: J1.5; also elsewhere on the board
HALL_A: C100.1, JP2.3, R101.2
HALL_A_IN: J1.14, R100.1, R101.1
HALL_B: C101.1, JP3.3, R104.2
HALL_B_IN: J1.15, R103.1, R104.1
HALL_C: C102.1, JP4.3, R107.2
HALL_C_IN: J1.16, R106.1, R107.1
HO0: J2.14, R50.1; also elsewhere on the board
HO1: J2.11, R52.1; also elsewhere on the board
HO2: J2.8, R54.1; also elsewhere on the board
HO3: J2.5, R56.1; also elsewhere on the board
I2C_SCL: J2.18, R115.2; also elsewhere on the board
I2C_SDA: J2.19, R114.2; also elsewhere on the board
IBUS_F: JP8.3; also elsewhere on the board
ISA_SEL: J1.17; also elsewhere on the board
ISB_SEL: J1.19; also elsewhere on the board
ISH: J1.18; also elsewhere on the board
LED_STAT_K: D3.1 (K), R112.1
LO0: J2.16, R51.1; also elsewhere on the board
LO1: J2.13, R53.1; also elsewhere on the board
LO2: J2.10, R55.1; also elsewhere on the board
LO3: J2.7, R57.1; also elsewhere on the board
NTC: C103.1, J1.10, R110.2; also elsewhere on the board
PD_PWR_EN: J1.3; also elsewhere on the board
QII_IN: C105.2; also elsewhere on the board
QII_SRC: C105.1, JP8.2
SENS_U: JP2.2; also elsewhere on the board
SENS_V: JP3.2; also elsewhere on the board
SENS_W: JP4.2; also elsewhere on the board
SW0: D10.1 (K), J2.15; also elsewhere on the board
SW1: D12.1 (K), J2.12; also elsewhere on the board
SW2: D14.1 (K), J2.9; also elsewhere on the board
SW3: D16.1 (K), J2.6; also elsewhere on the board
SWDIO: J1.8; also elsewhere on the board
TACH_IN: J1.20, R123.1
TACH_R: JP8.1, R123.2
UART_RX: J2.2; also elsewhere on the board
UART_TX: J2.3; also elsewhere on the board
USB_VBUS: J1.1, J1.2; also elsewhere on the board
VBUS: J1.9; also elsewhere on the board
VBUS_SNS: J2.17; also elsewhere on the board
nFAULT: C120.1, R120.2, R122.2; also elsewhere on the board
nFAULT_IN: J2.20, R120.1
nRST: J2.4; also elsewhere on the board

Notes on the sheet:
DIP 端子 (2.54mm, 21 ピン x 2 列, 列間 17.78mm)
ゲート確認 LED (モジュール上面に 8 個: 子基板の部品面はヒートシンク側で見えないため)
3 相センシング選択 (はんだジャンパ, 出荷時 1-2 = 相電圧) / QII 入力選択
ホール入力 / USER・BOOT + 状態 LED / I2C / nFAULT / NTC
子基板は同じピン番号のソケット (左右対称) で受ける。
H: HOx-SWx (ハイサイドのゲート電圧), L: LOx-GND。約 0.35mA @ VDD8=10V。PWM のデューティで明るさが変わる。
子基板を付けずブレッドボードで使うときも同じ: BEMF_x / HALL_x_IN ピンに信号を入れる。
NTC 本体は子基板 (MOSFET 近傍)。PA4 の ISOURCE1 で駆動。I2C プルアップ R114/R115 は必要時のみ。

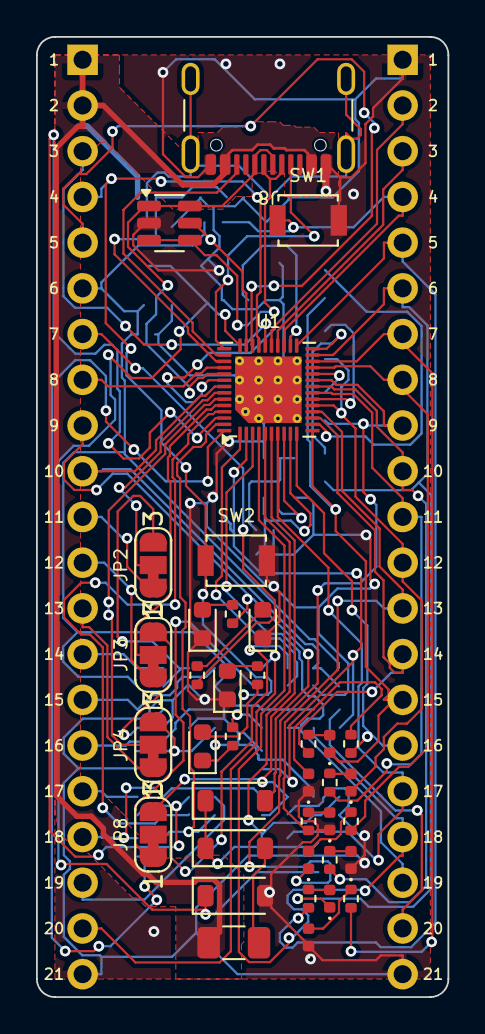
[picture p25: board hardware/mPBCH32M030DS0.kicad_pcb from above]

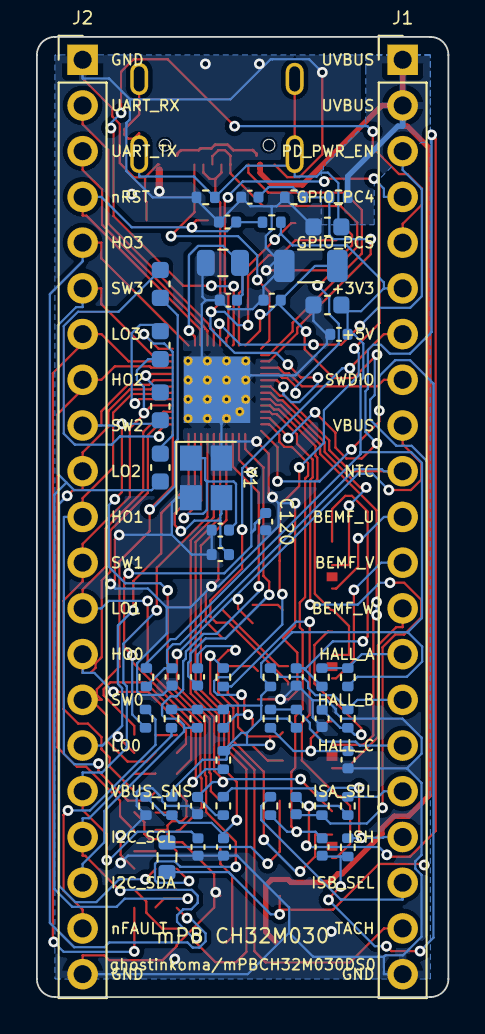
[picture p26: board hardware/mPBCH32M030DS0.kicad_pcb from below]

Board: 2 copper layers, 22.9 x 53.3 mm, 91 parts (54 on the bottom side), 83 nets.

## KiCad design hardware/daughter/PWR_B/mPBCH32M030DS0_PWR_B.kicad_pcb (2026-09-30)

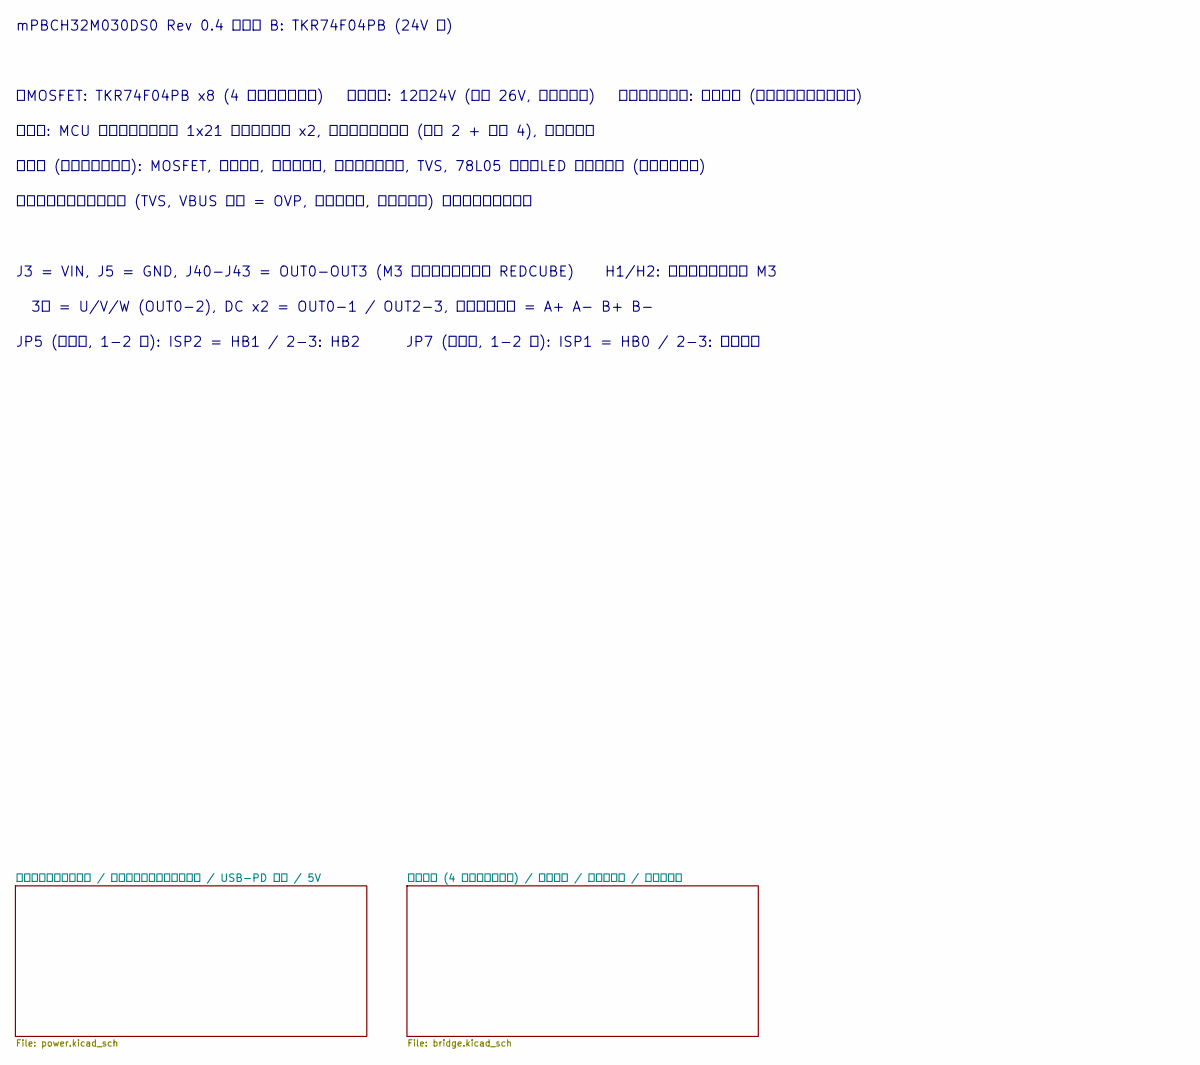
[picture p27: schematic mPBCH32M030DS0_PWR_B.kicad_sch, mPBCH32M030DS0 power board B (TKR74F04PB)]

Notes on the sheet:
mPBCH32M030DS0 Rev 0.4 子基板 B: TKR74F04PB (24V 系)
・MOSFET: TKR74F04PB x8 (4 ハーフブリッジ) 入力電圧: 12〜24V (上限 26V, 安定化電源) 出力電流の目安: 銅箔律速 (電流容量チェック参照)
・上面: MCU モジュールを挿す 1x21 ピンソケット x2, 丸端子用ネジ端子 (電源 2 + 出力 4), バルク容量
・下面 (ヒートシンク側): MOSFET, シャント, ゲート抵抗, 理想ダイオード, TVS, 78L05 など。LED は置かない (モジュール側)
・電圧系に依存する部品 (TVS, VBUS 分圧 = OVP, バルク容量, 相電圧分圧) はこの基板で決める
J3 = VIN, J5 = GND, J40-J43 = OUT0-OUT3 (M3 丸端子用ネジ端子 REDCUBE) H1/H2: ヒートシンク固定 M3
3相 = U/V/W (OUT0-2), DC x2 = OUT0-1 / OUT2-3, ステッピング = A+ A- B+ B-
JP5 (はんだ, 1-2 済): ISP2 = HB1 / 2-3: HB2 JP7 (はんだ, 1-2 済): ISP1 = HB0 / 2-3: バス電流

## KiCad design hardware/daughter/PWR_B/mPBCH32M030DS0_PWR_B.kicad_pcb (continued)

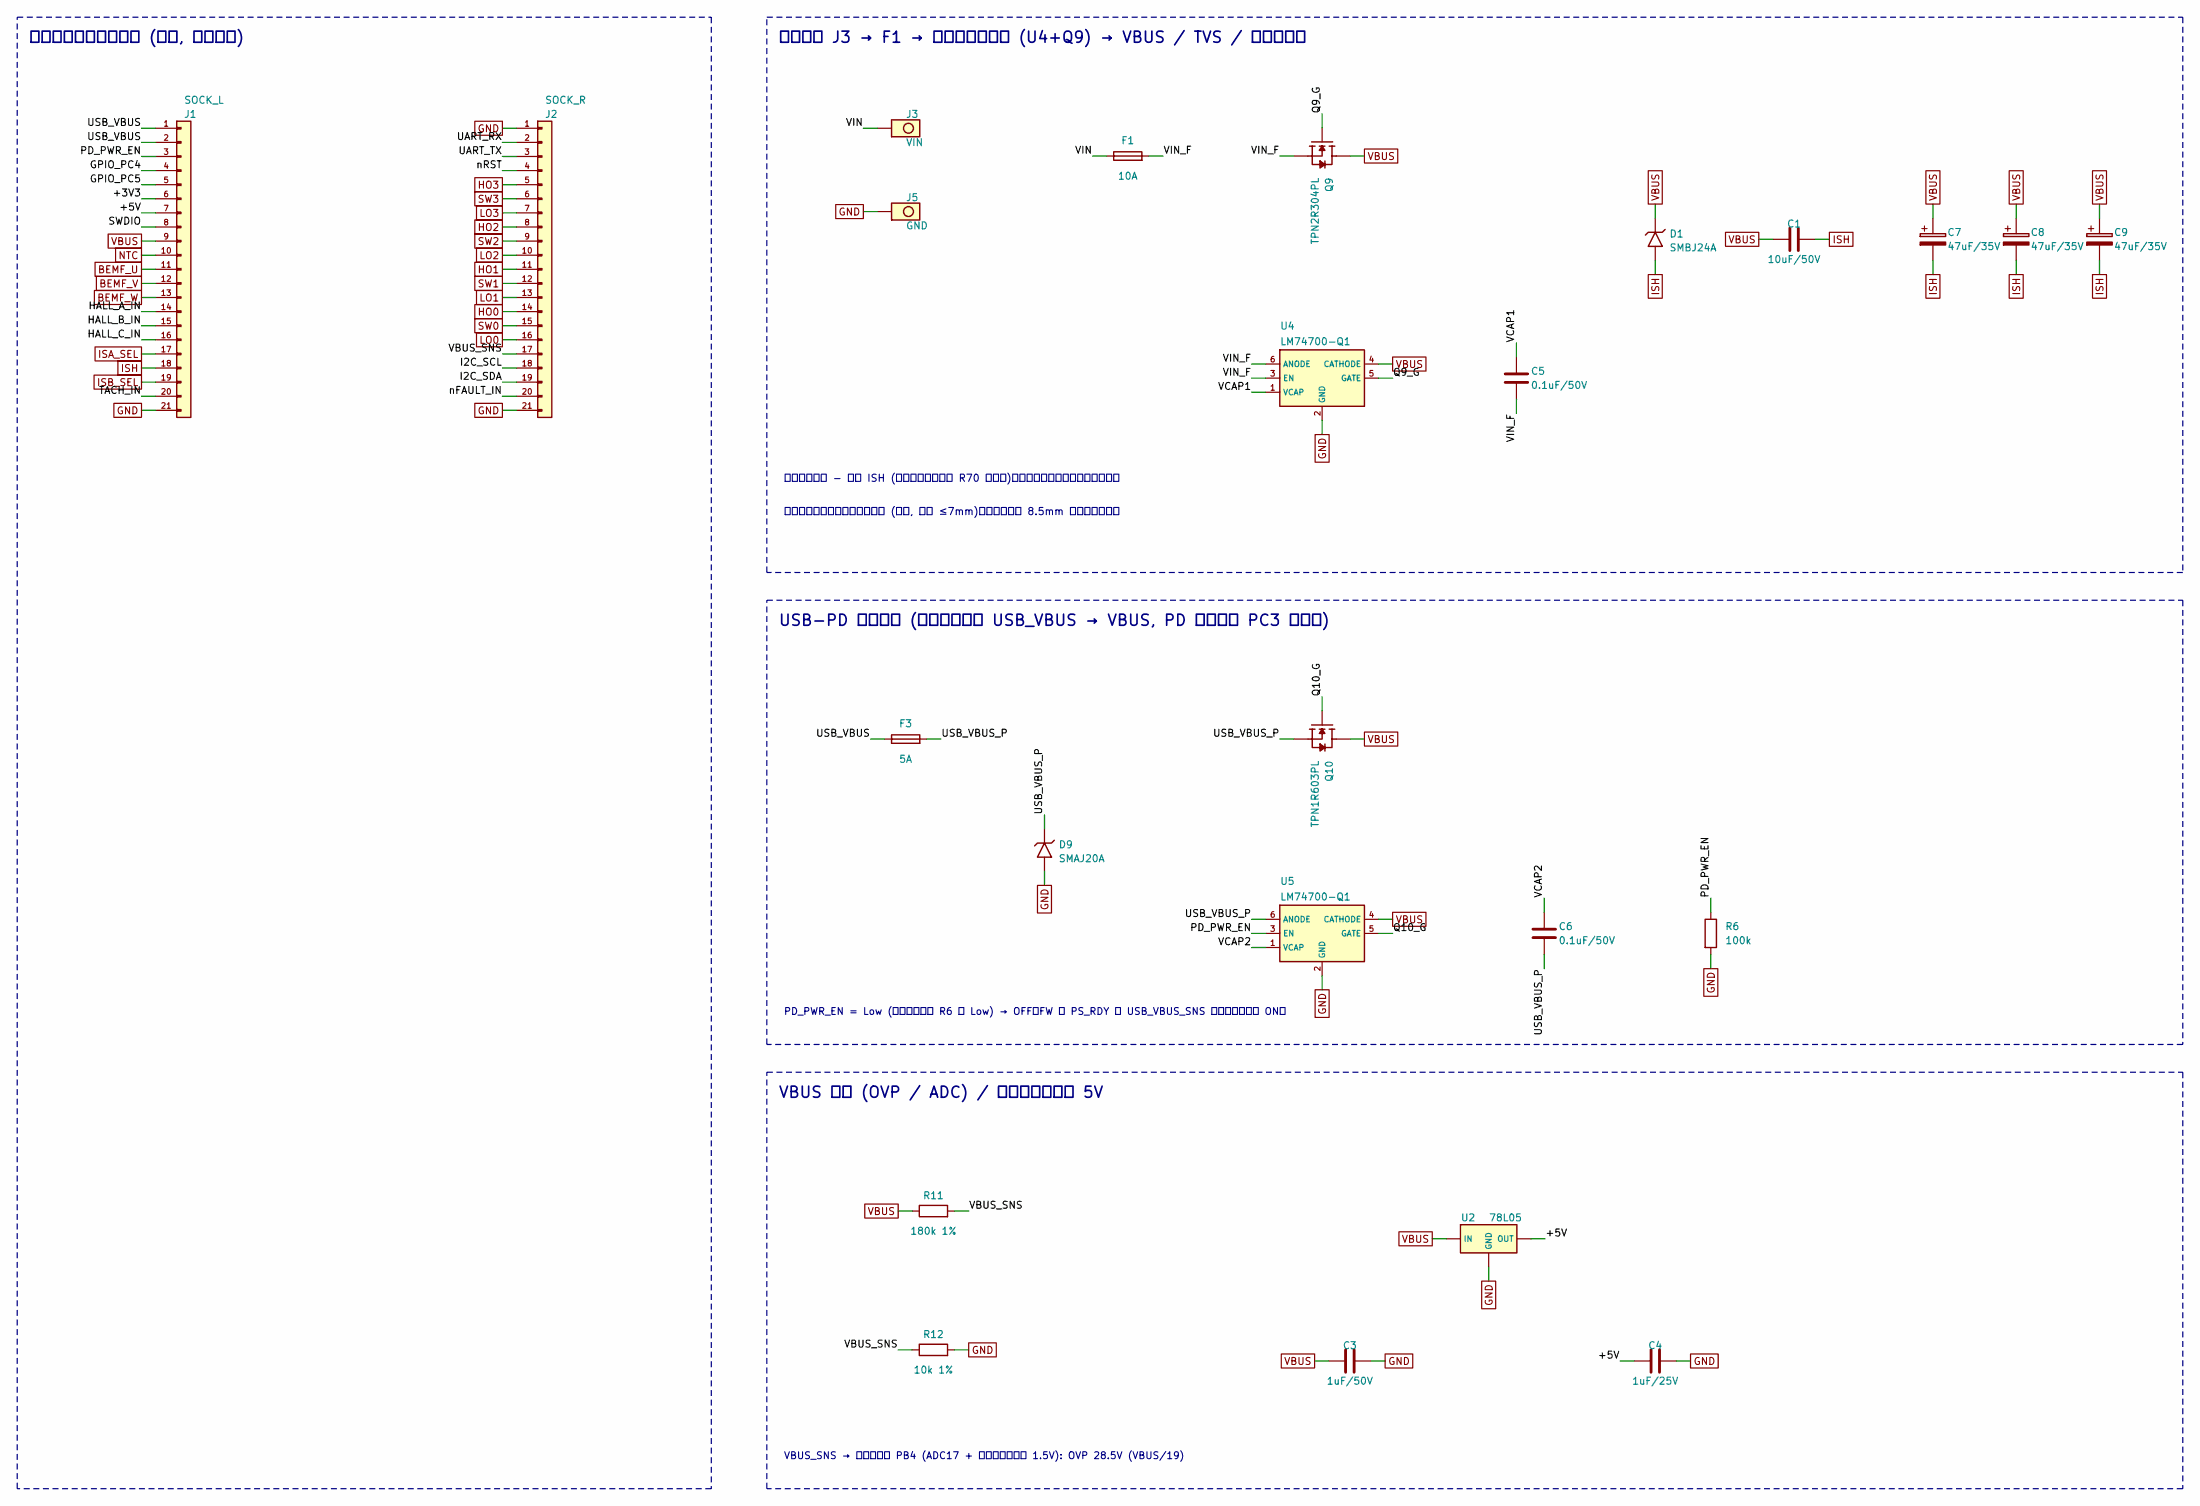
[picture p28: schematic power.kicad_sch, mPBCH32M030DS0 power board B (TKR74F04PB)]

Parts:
C1: 10uF/50V; C_1206_3216Metric; MPN Murata GRM31CR61H106KA12L (X5R 1206)
C3: 1uF/50V; C_0603_1608Metric; MPN Murata GRM188R61H105KAALD (X5R 1608)
C4: 1uF/25V; C_0402_1005Metric; MPN Murata GRM155R61E105KA12D (X5R 1005)
C5, C6: 0.1uF/50V; C_0402_1005Metric; MPN Murata GRM155R71H104KE14D (X7R 1005)
C7, C8, C9: 47uF/35V; CP_Elec_6.3x5.9; MPN Panasonic EEE-FK1V470P (6.3x6.1mm)
D1: SMBJ24A; D_SMB; MPN SMBJ24A (Vwm 24V)
D9: SMAJ20A; D_SMA; MPN SMAJ20A (USB 側サージ)
F1: 10A; Fuse_Littelfuse_NANO2_2410; MPN Littelfuse 0451010.MRL (NANO2 2410, 10A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
F3: 5A; Fuse_1812_4532Metric; MPN 1812 5A 速断ヒューズ (例: Bourns SF-1812F500)
J1: SOCK_L; PinSocket_1x21_P2.54mm_Vertical; MPN 2.54mm 1x21 ピンソケット (標準 8.5mm 高)
J2: SOCK_R; PinSocket_1x21_P2.54mm_Vertical; MPN 2.54mm 1x21 ピンソケット (標準 8.5mm 高)
J3: VIN; Wuerth_REDCUBE-THR_WP-THRBU_74650073_THR; MPN Würth REDCUBE THR WP-THRBU 74650073 (M3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
J5: GND; Wuerth_REDCUBE-THR_WP-THRBU_74650073_THR; MPN Würth REDCUBE THR WP-THRBU 74650073 (M3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
Q9: TPN2R304PL; Vishay_PowerPAK_1212-8_Single; MPN Toshiba TPN2R304PL,L1Q (40V 2.3mΩ, 理想ダイ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
Q10: TPN1R603PL; Vishay_PowerPAK_1212-8_Single; MPN Toshiba TPN1R603PL,L1Q (USB 側 理想ダイオード)
R6: 100k; R_0402_1005Metric
R11: 180k 1%; R_0402_1005Metric
R12: 10k 1%; R_0402_1005Metric
U2: 78L05; SOT-89-3; MPN 78L05 (SOT-89, Vin ≤30V)
U4, U5: LM74700-Q1; SOT-23-6; MPN TI LM74700QDBVRQ1

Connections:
+3V3: J1.6
+5V: C4.1, J1.7, U2.1 (OUT)
BEMF_U: J1.11; also elsewhere on the board
BEMF_V: J1.12; also elsewhere on the board
BEMF_W: J1.13; also elsewhere on the board
GND: C3.2, C4.2, D9.2 (A), J1.21, J2.1, J2.21, J5.1, R6.2, R12.2, U2.2 (GND), U4.2 (GND), U5.2 (GND); also elsewhere on the board
GPIO_PC4: J1.4
GPIO_PC5: J1.5
HALL_A_IN: J1.14
HALL_B_IN: J1.15
HALL_C_IN: J1.16
HO0: J2.14; also elsewhere on the board
HO1: J2.11; also elsewhere on the board
HO2: J2.8; also elsewhere on the board
HO3: J2.5; also elsewhere on the board
I2C_SCL: J2.18
I2C_SDA: J2.19
ISA_SEL: J1.17; also elsewhere on the board
ISB_SEL: J1.19; also elsewhere on the board
ISH: C1.2, C7.2, C8.2, C9.2, D1.2 (A), J1.18; also elsewhere on the board
LO0: J2.16; also elsewhere on the board
LO1: J2.13; also elsewhere on the board
LO2: J2.10; also elsewhere on the board
LO3: J2.7; also elsewhere on the board
NTC: J1.10; also elsewhere on the board
PD_PWR_EN: J1.3, R6.1, U5.3 (EN)
Q9_G: Q9.4 (G), U4.5 (GATE)
Q10_G: Q10.4 (G), U5.5 (GATE)
SW0: J2.15; also elsewhere on the board
SW1: J2.12; also elsewhere on the board
SW2: J2.9; also elsewhere on the board
SW3: J2.6; also elsewhere on the board
SWDIO: J1.8
TACH_IN: J1.20
UART_RX: J2.2
UART_TX: J2.3
USB_VBUS: F3.1, J1.1, J1.2
USB_VBUS_P: C6.2, D9.1 (K), F3.2, Q10.1 (S), Q10.2 (S), Q10.3 (S), U5.6 (ANODE)
VBUS: C1.1, C3.1, C7.1, C8.1, C9.1, D1.1 (K), J1.9, Q9.5 (D), Q10.5 (D), R11.1, U2.3 (IN), U4.4 (CATHODE), U5.4 (CATHODE); also elsewhere on the board
VBUS_SNS: J2.17, R11.2, R12.1
VCAP1: C5.1, U4.1 (VCAP)
VCAP2: C6.1, U5.1 (VCAP)
VIN: F1.1, J3.1
VIN_F: C5.2, F1.2, Q9.1 (S), Q9.2 (S), Q9.3 (S), U4.3 (EN), U4.6 (ANODE)
nFAULT_IN: J2.20
nRST: J2.4

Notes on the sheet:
モジュール用ソケット (上面, 左右対称)
電源入力 J3 → F1 → 理想ダイオード (U4+Q9) → VBUS / TVS / バルク容量
USB-PD 給電経路 (モジュールの USB_VBUS → VBUS, PD 契約後に PC3 で許可)
VBUS 分圧 (OVP / ADC) / ホールセンサ用 5V
バルク容量の − 側は ISH (バス電流シャント R70 の手前)。レッグの帰路に最短でつなぐ。
バルク容量はモジュールの真下 (上面, 高さ ≤7mm)。ソケット高 8.5mm の下に収まる。
PD_PWR_EN = Low (リセット中も R6 で Low) → OFF。FW が PS_RDY と USB_VBUS_SNS を確認してから ON。
VBUS_SNS → モジュール PB4 (ADC17 + 過電圧リセット 1.5V): OVP 28.5V (VBUS/19)

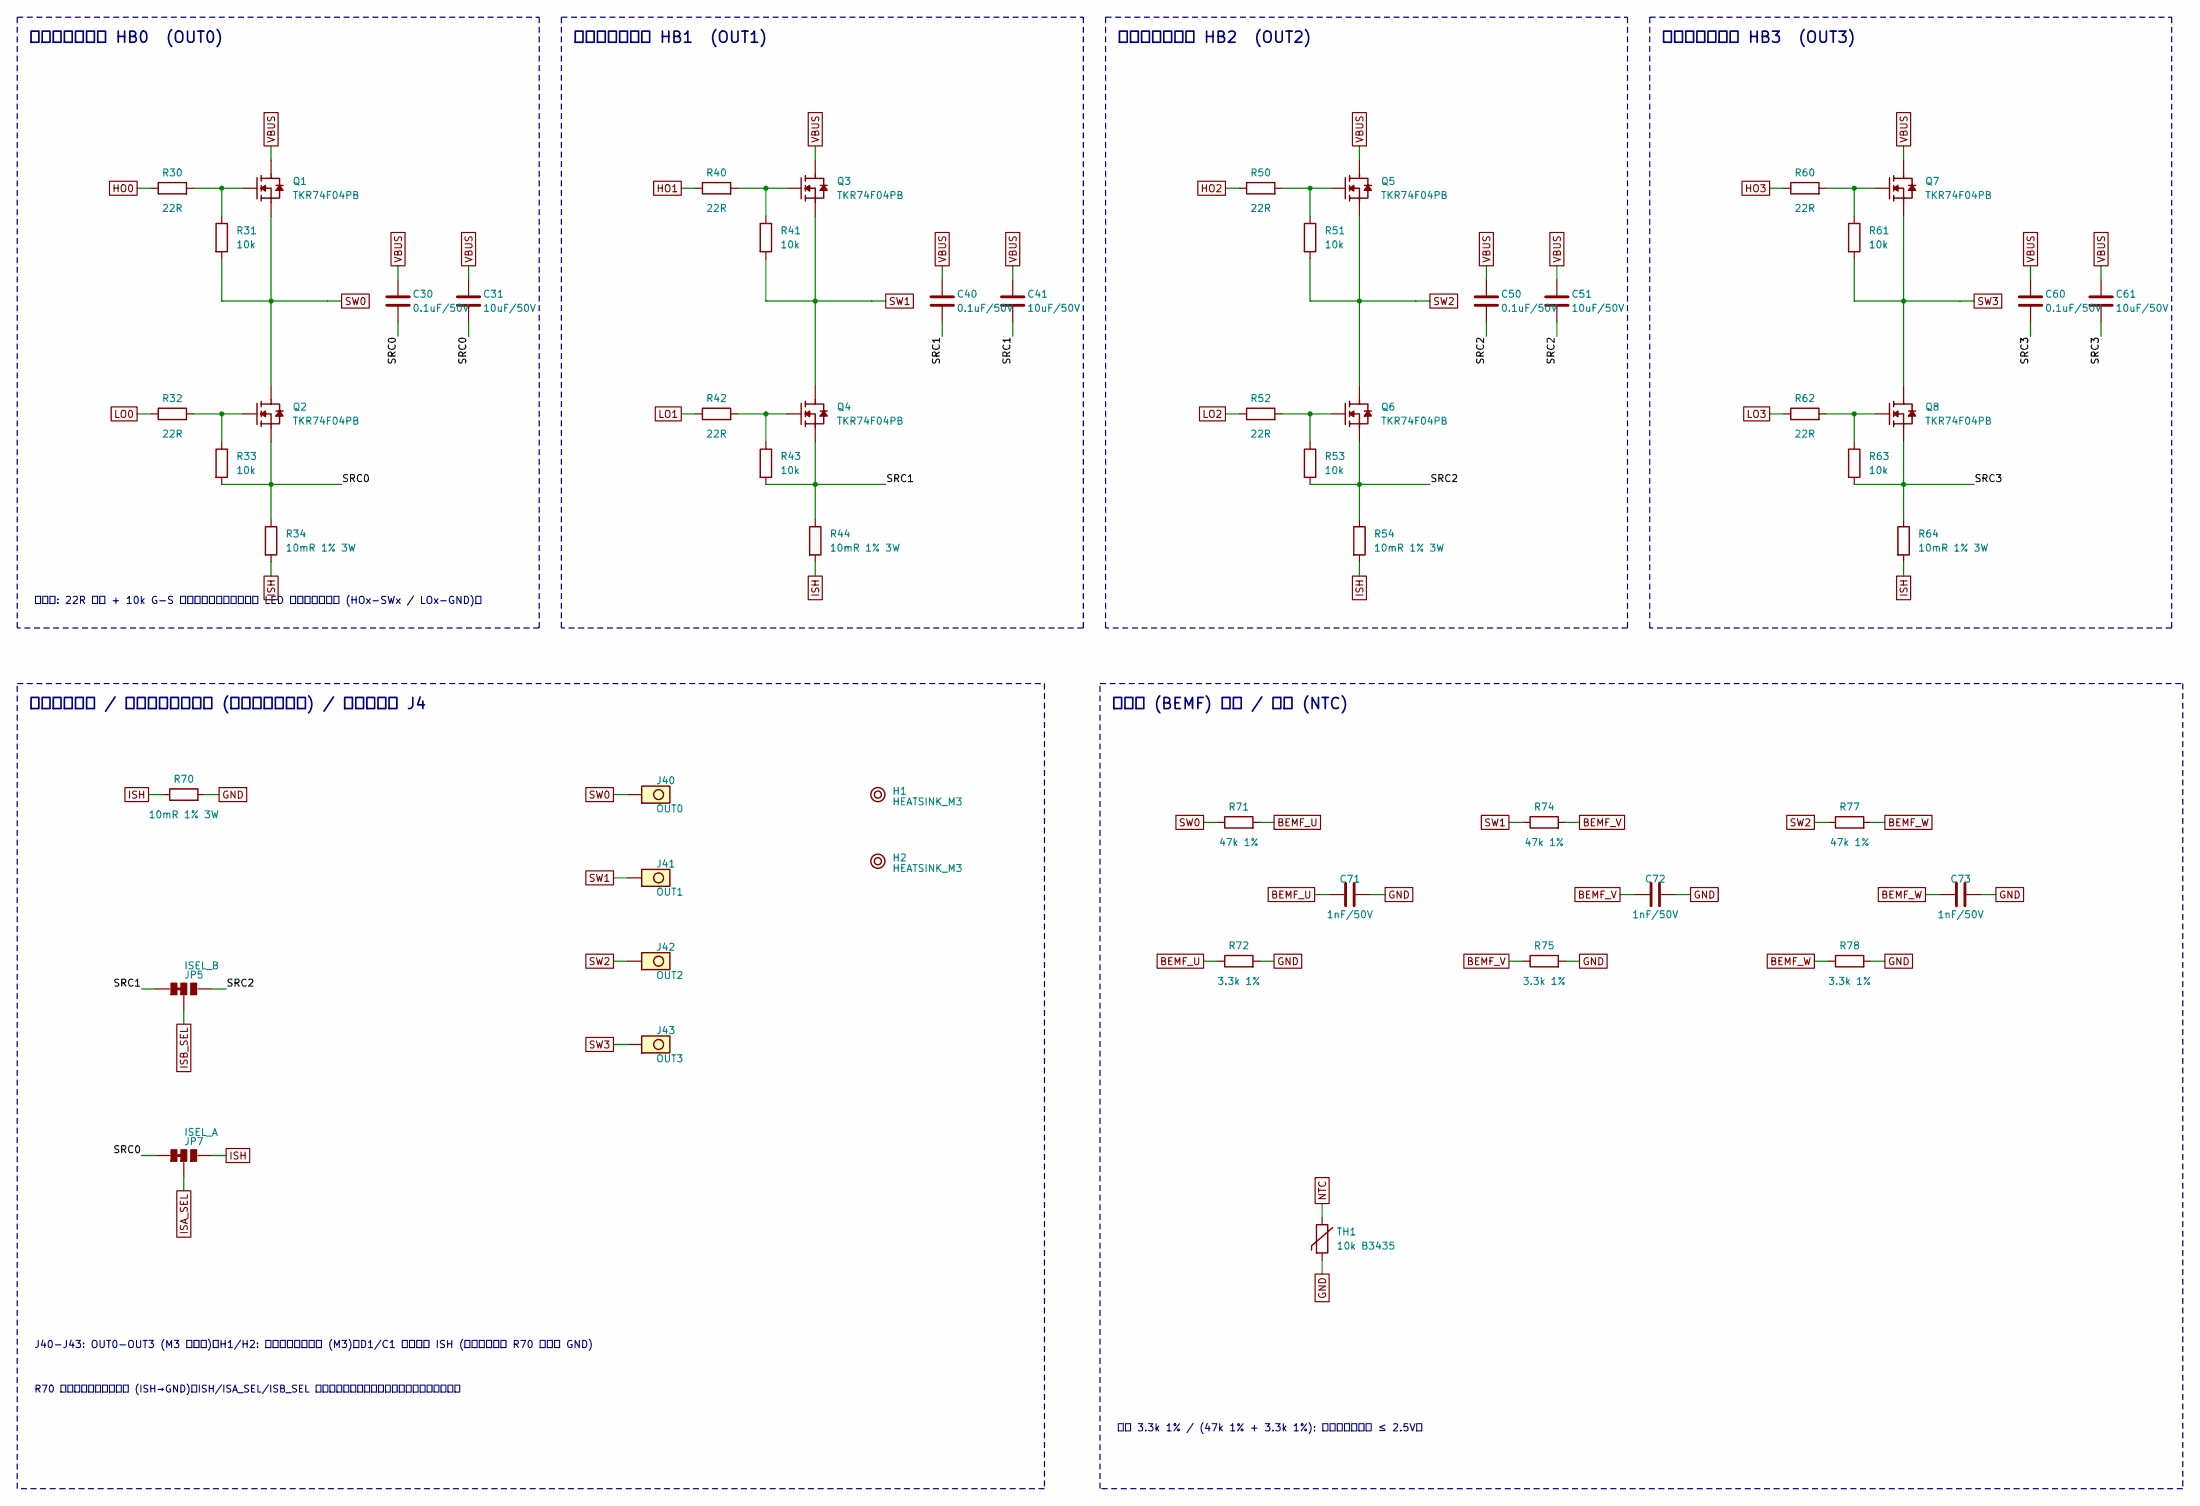
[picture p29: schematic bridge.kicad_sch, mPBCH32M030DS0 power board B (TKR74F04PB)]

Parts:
C30, C40, C50, C60: 0.1uF/50V; C_0402_1005Metric; MPN Murata GRM155R71H104KE14D (X7R 1005)
C31, C41, C51, C61: 10uF/50V; C_1206_3216Metric; MPN Murata GRM31CR61H106KA12L (X5R 1206)
C71, C72, C73: 1nF/50V; C_0402_1005Metric; MPN Murata GRM155R71H102KA01D (X7R 1005)
H1, H2: HEATSINK_M3; MountingHole_3.2mm_M3; MPN ヒートシンク固定用 M3 穴 (非めっき)
J40: OUT0; Wuerth_REDCUBE-THR_WP-THRBU_74650073_THR; MPN Würth REDCUBE THR WP-THRBU 74650073 (M3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
J41: OUT1; Wuerth_REDCUBE-THR_WP-THRBU_74650073_THR; MPN Würth REDCUBE THR WP-THRBU 74650073 (M3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
J42: OUT2; Wuerth_REDCUBE-THR_WP-THRBU_74650073_THR; MPN Würth REDCUBE THR WP-THRBU 74650073 (M3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
J43: OUT3; Wuerth_REDCUBE-THR_WP-THRBU_74650073_THR; MPN Würth REDCUBE THR WP-THRBU 74650073 (M3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
JP5: ISEL_B; SolderJumper-3_P1.3mm_Bridged12_RoundedPad1.0x1.5mm_NumberL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; MPN はんだジャンパ 3 端子 (1-2 ブリッジ済み: HB1 / 2-3: HB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
JP7: ISEL_A; SolderJumper-3_P1.3mm_Bridged12_RoundedPad1.0x1.5mm_NumberL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; MPN はんだジャンパ 3 端子 (1-2 ブリッジ済み: HB0 レッグ / 2-3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
Q1, Q2, Q3, Q4, Q5, Q6, Q7, Q8: TKR74F04PB; TO-263-2; MPN Toshiba TKR74F04PB,LQ (40V 0.74mΩ TO-22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
R30, R32, R40, R42, R50, R52, R60, R62: 22R; R_0402_1005Metric
R31, R33, R41, R43, R51, R53, R61, R63: 10k; R_0402_1005Metric
R34, R44, R54, R64, R70: 10mR 1% 3W; R_2512_6332Metric; MPN 2512 3W (例: Bourns CRE2512-FZ-R010E-3)
R71, R74, R77: 47k 1%; R_0402_1005Metric
R72, R75, R78: 3.3k 1%; R_0402_1005Metric
TH1: 10k B3435; R_0402_1005Metric; MPN NTC 10kΩ B3435 1005 (例: Murata NCP15XH1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

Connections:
BEMF_U: C71.1, R71.2, R72.1; also elsewhere on the board
BEMF_V: C72.1, R74.2, R75.1; also elsewhere on the board
BEMF_W: C73.1, R77.2, R78.1; also elsewhere on the board
GH0: Q1.1 (G), R30.2, R31.1
GH1: Q3.1 (G), R40.2, R41.1
GH2: Q5.1 (G), R50.2, R51.1
GH3: Q7.1 (G), R60.2, R61.1
GL0: Q2.1 (G), R32.2, R33.1
GL1: Q4.1 (G), R42.2, R43.1
GL2: Q6.1 (G), R52.2, R53.1
GL3: Q8.1 (G), R62.2, R63.1
GND: C71.2, C72.2, C73.2, R70.2, R72.2, R75.2, R78.2, TH1.2; also elsewhere on the board
HO0: R30.1; also elsewhere on the board
HO1: R40.1; also elsewhere on the board
HO2: R50.1; also elsewhere on the board
HO3: R60.1; also elsewhere on the board
ISA_SEL: JP7.2; also elsewhere on the board
ISB_SEL: JP5.2; also elsewhere on the board
ISH: JP7.3, R34.2, R44.2, R54.2, R64.2, R70.1; also elsewhere on the board
LO0: R32.1; also elsewhere on the board
LO1: R42.1; also elsewhere on the board
LO2: R52.1; also elsewhere on the board
LO3: R62.1; also elsewhere on the board
NTC: TH1.1; also elsewhere on the board
SRC0: C30.2, C31.2, JP7.1, Q2.3 (S), R33.2, R34.1
SRC1: C40.2, C41.2, JP5.1, Q4.3 (S), R43.2, R44.1
SRC2: C50.2, C51.2, JP5.3, Q6.3 (S), R53.2, R54.1
SRC3: C60.2, C61.2, Q8.3 (S), R63.2, R64.1
SW0: J40.1, Q1.3 (S), Q2.2 (D), R31.2, R71.1; also elsewhere on the board
SW1: J41.1, Q3.3 (S), Q4.2 (D), R41.2, R74.1; also elsewhere on the board
SW2: J42.1, Q5.3 (S), Q6.2 (D), R51.2, R77.1; also elsewhere on the board
SW3: J43.1, Q7.3 (S), Q8.2 (D), R61.2; also elsewhere on the board
VBUS: C30.1, C31.1, C40.1, C41.1, C50.1, C51.1, C60.1, C61.1, Q1.2 (D), Q3.2 (D), Q5.2 (D), Q7.2 (D); also elsewhere on the board

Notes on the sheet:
ハーフブリッジ HB0 (OUT0)
ハーフブリッジ HB1 (OUT1)
ハーフブリッジ HB2 (OUT2)
ハーフブリッジ HB3 (OUT3)
バスシャント / 電流チャネル選択 (はんだジャンパ) / モータ出力 J4
相電圧 (BEMF) 分圧 / 温度 (NTC)
ゲート: 22R 直列 + 10k G-S プルダウン。ゲート確認 LED はモジュール側 (HOx-SWx / LOx-GND)。
J40-J43: OUT0-OUT3 (M3 丸端子)。H1/H2: ヒートシンク固定 (M3)。D1/C1 の帰りは ISH (バスシャント R70 経由で GND)
R70 は全レッグ共通の帰路 (ISH→GND)。ISH/ISA_SEL/ISB_SEL はシャント端からケルビン配線でソケットへ。
分圧 3.3k 1% / (47k 1% + 3.3k 1%): 入力電圧上限で ≤ 2.5V。

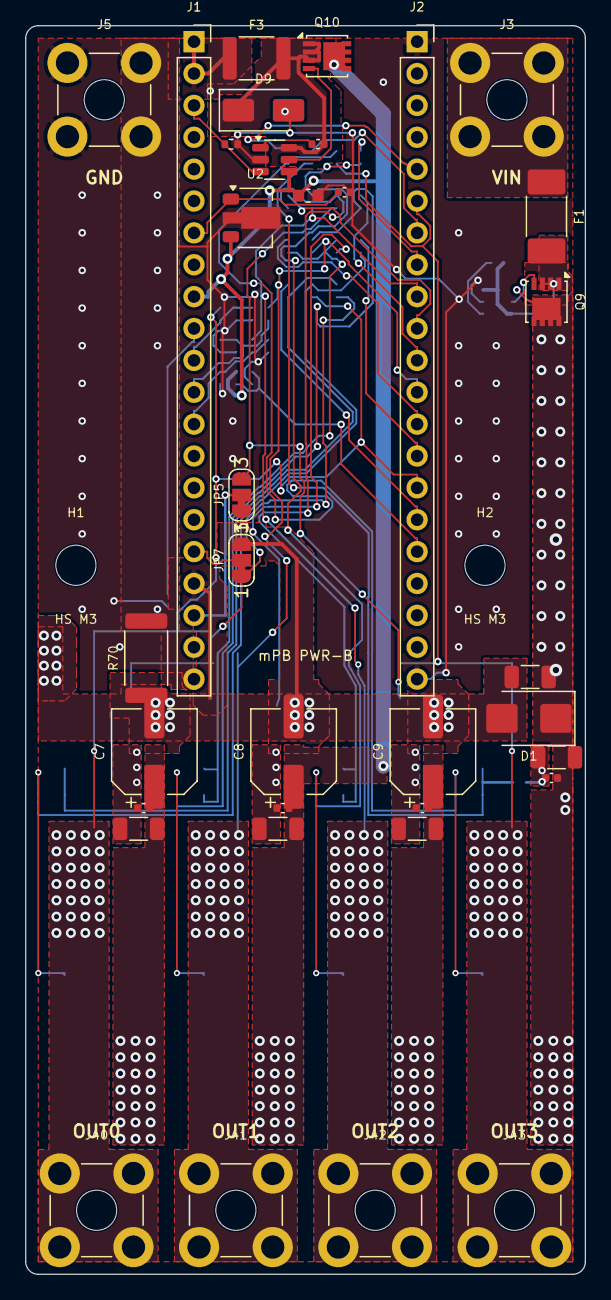
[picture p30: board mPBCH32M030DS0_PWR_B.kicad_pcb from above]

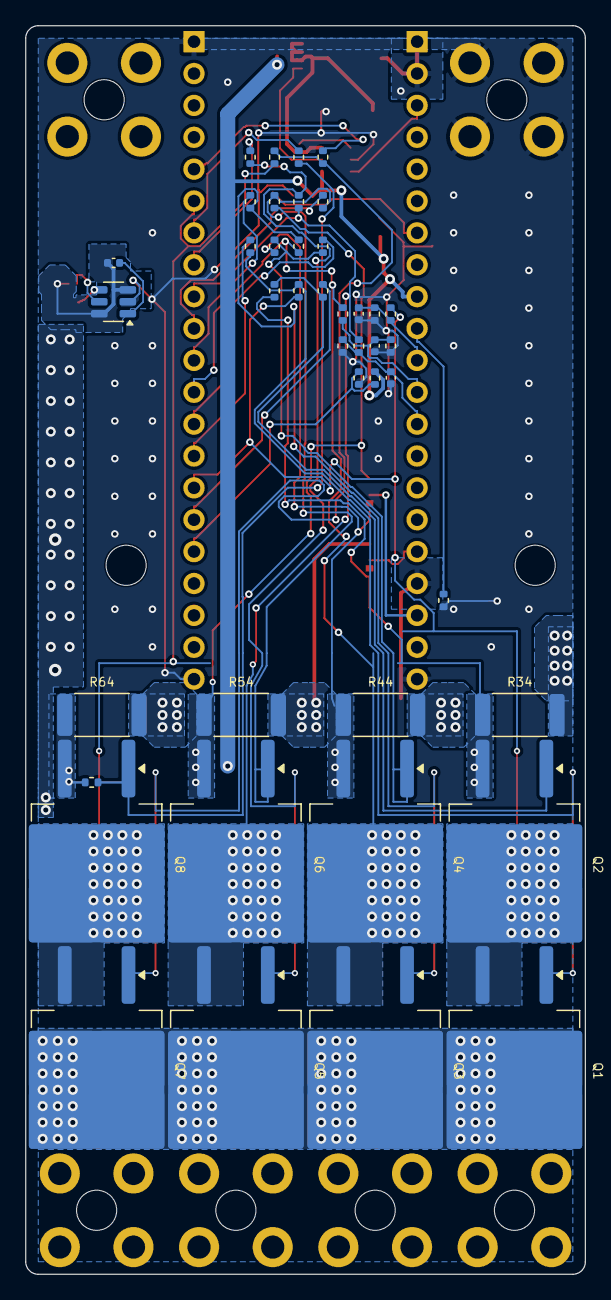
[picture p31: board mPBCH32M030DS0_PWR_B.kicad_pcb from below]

Board: 2 copper layers, 44.6 x 99.5 mm, 79 parts (42 on the bottom side), 44 nets.

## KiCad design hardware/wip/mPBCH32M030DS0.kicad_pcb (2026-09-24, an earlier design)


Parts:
C1, C2, C3, C4, C5, C6, C7: 100n; C_0402_1005Metric
C8: 10u; C_0603_1608Metric
CH32M030C8U1: CH32M030DS0_QFN48
J1: USB_C_Receptacle_USB2.0_14P; USB_C_Receptacle_GCT_USB4105-xx-A_16P_TopMnt_Horizontal
Q1: TPN1R603PL,L1Q; SON-8-1EP_3x2mm_P0.5mm_EP1.4x1.6mm; Manufacturer_Part_Number TPN1R603PL,L1Q; Mouser Part Number 757-TPN1R603PLL1Q
R1: 1K; R_0402_1005Metric
X1: ASCO; Oscillator_SMD_Abracon_ASCO-4Pin_1.6x1.2mm

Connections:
GND: C5.1, C6.1, C7.1, C8.1, CH32M030C8U1.0 (GND), J1.A1 (GND), J1.A12 (GND), J1.B1 (GND), J1.B12 (GND), J1.S1 (SHIELD), X1.2 (GND)
unnamed: CH32M030C8U1.37 (PA0/CC1R/A13), J1.A5 (CC1)
unnamed: CH32M030C8U1.38 (PA1/CC2R/A14), J1.B5 (CC2)
unnamed: CH32M030C8U1.41 (PB0/UDP/T2C2_/CM3P1/A11), J1.A6 (D+), J1.B6 (D+)
unnamed: CH32M030C8U1.42 (PB1/UDM/T2C3_/CM3P2/A12), J1.A7 (D-), J1.B7 (D-)
unnamed: CH32M030C8U1.10 (PB5/XI/CM2P/A3), X1.3 (OUT)
unnamed: C1.1, CH32M030C8U1.14 (VB0)
unnamed: C2.2, CH32M030C8U1.18 (VB1)
unnamed: C3.2, CH32M030C8U1.22 (VB2)
unnamed: C4.2, CH32M030C8U1.26 (VB3)
unnamed: C6.2, CH32M030C8U1.35 (VDD33)
unnamed: C7.2, CH32M030C8U1.36 (VHV)
unnamed: C1.2, CH32M030C8U1.13 (VS0)
unnamed: C2.1, CH32M030C8U1.17 (VS1)
unnamed: C3.1, CH32M030C8U1.21 (VS2)
unnamed: C4.1, CH32M030C8U1.25 (VS3)
unnamed: R1.2, X1.1 (Tri-State)
VDD: C5.2, C8.2, CH32M030C8U1.28 (VDD8), J1.A4 (VBUS), J1.A9 (VBUS), J1.B4 (VBUS), J1.B9 (VBUS), R1.1, X1.4 (VDD)

Board: 2 copper layers, 13 parts (0 on the bottom side), 18 nets, no tracks yet.

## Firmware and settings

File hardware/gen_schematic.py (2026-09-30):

#!/usr/bin/env python3
"""
CH32M030 ユニバーサル・モータードライバ基板 回路図ジェネレータ (KiCad 7 形式)

  python3 gen_schematic.py   -> 主基板 (hardware/) と子基板 (hardware/daughter/PWR_A〜D/) の
                               *.kicad_sch / *.kicad_pro / bom.csv / expected_nets.txt / parts.json を生成
                               (parts.json は gen_pcb.py が基板を作るときの部品・ネット表)

外部ライブラリに依存しないよう、使用シンボルはすべてこのスクリプト内で定義し
回路図ファイルへ埋め込む。各ピンは短いワイヤ + ネットラベルで接続する
(複数シートにまたがるネットはグローバルラベル、それ以外はローカルラベル)。
回路の「正」はこのファイルの部品表(ネット割当)であり、配置は見やすさのためのもの。
"""
import csv
import math
import os
import uuid

OUT = os.path.dirname(os.path.abspath(__file__))
NS = uuid.UUID("6b1f3c2e-8d5a-4f0e-9c1a-2a7d3e4b5c60")
REV = "0.4"
DATE = "2026-09-26"
CUR = None  # 出力中の Project


def U(key):
    return str(uuid.uuid5(NS, key))


# ---------------------------------------------------------------------------
# シンボル定義 (lib 座標は y 上向き)
#   pin: (number, name, x, y, angle, length, hidden)
#   angle: ピンが接続点から本体へ伸びる向き (0=右, 90=上, 180=左, 270=下)
# ---------------------------------------------------------------------------
def _pl(pts, w=0.254, fill="none"):
    p = " ".join(f"(xy {x:g} {y:g})" for x, y in pts)
    return f"(polyline (pts {p}) (stroke (width {w}) (type default)) (fill (type {fill})))"


def _rect(x0, y0, x1, y1, w=0.254, fill="none"):
    return (f"(rectangle (start {x0:g} {y0:g}) (end {x1:g} {y1:g}) "
            f"(stroke (width {w}) (type default)) (fill (type {fill})))")


def _circ(x, y, r, w=0.254, fill="none"):
    return (f"(circle (center {x:g} {y:g}) (radius {r:g}) "
            f"(stroke (width {w}) (type default)) (fill (type {fill})))")


def _text(s, x, y, size=1.27):
    return f'(text "{s}" (at {x:g} {y:g} 0) (effects (font (size {size} {size}))))'


SYMS = {}


def defsym(name, prefix, pins, gfx, show_pin_names=False, show_pin_numbers=False,
           ref_at=(2.54, 1.27), val_at=(2.54, -1.27)):
    SYMS[name] = dict(prefix=prefix, pins=pins, gfx=gfx, spn=show_pin_names,
                      spnum=show_pin_numbers, ref_at=ref_at, val_at=val_at)


# 2 端子 (縦置き基準: pin1 上, pin2 下)
defsym("R", "R", [("1", "~", 0, 3.81, 270, 1.27, False), ("2", "~", 0, -3.81, 90, 1.27, False)],
       [_rect(-1.016, -2.54, 1.016, 2.54)])
defsym("C", "C", [("1", "~", 0, 3.81, 270, 3.048, False), ("2", "~", 0, -3.81, 90, 3.048, False)],
       [_pl([(-2.032, 0.762), (2.032, 0.762)], 0.508), _pl([(-2.032, -0.762), (2.032, -0.762)], 0.508)])
defsym("CP", "C", [("1", "~", 0, 3.81, 270, 2.794, False), ("2", "~", 0, -3.81, 90, 2.794, False)],
       [_rect(-2.286, 0.508, 2.286, 1.016), _rect(-2.286, -1.016, 2.286, -0.508, fill="outline"),
        _text("+", -1.524, 2.032)])
defsym("FUSE", "F", [("1", "~", 0, 3.81, 270, 1.27, False), ("2", "~", 0, -3.81, 90, 1.27, False)],
       [_rect(-0.762, -2.54, 0.762, 2.54), _pl([(0, 2.54), (0, -2.54)])])
defsym("NTC", "TH", [("1", "~", 0, 3.81, 270, 1.27, False), ("2", "~", 0, -3.81, 90, 1.27, False)],
       [_rect(-1.016, -2.54, 1.016, 2.54), _pl([(-1.905, -2.032), (-1.905, -1.27), (1.905, 2.032)])])
# ダイオード類 (横置き基準: pin1=K 左, pin2=A 右)
_dtri = _pl([(1.27, 1.27), (1.27, -1.27), (-1.27, 0), (1.27, 1.27)])
defsym("D_TVS", "D", [("1", "K", -3.81, 0, 0, 2.54, False), ("2", "A", 3.81, 0, 180, 2.54, False)],
       [_dtri, _pl([(-1.778, 1.778), (-1.27, 1.27), (-1.27, -1.27), (-0.762, -1.778)])])
defsym("D_ZENER", "D", [("1", "K", -3.81, 0, 0, 2.54, False), ("2", "A", 3.81, 0, 180, 2.54, False)],
       [_dtri, _pl([(-1.778, 1.27), (-1.27, 1.27), (-1.27, -1.27), (-0.762, -1.27)])])
defsym("LED", "D", [("1", "K", -3.81, 0, 0, 2.54, False), ("2", "A", 3.81, 0, 180, 2.54, False)],
       [_dtri, _pl([(-1.27, 1.27), (-1.27, -1.27)]),
        _pl([(-0.508, 1.778), (0.508, 2.794)]), _pl([(0.508, 1.778), (1.524, 2.794)])])
# N-ch MOSFET (TSON Advance / PowerPAK1212-8 互換ランド: 1-3=S, 4=G, 5=D 大パッド)
_mos = [
    _pl([(-2.54, -1.905), (-2.54, 1.905)]),
    _pl([(-1.778, 1.27), (-1.778, 2.286)]), _pl([(-1.778, -0.508), (-1.778, 0.508)]),
    _pl([(-1.778, -2.286), (-1.778, -1.27)]),
    _pl([(-1.778, 1.778), (0, 1.778), (0, 2.54)]), _pl([(-1.778, -1.778), (0, -1.778), (0, -2.54)]),
    _pl([(-1.778, 0), (0, 0), (0, -1.778)]),
    _pl([(-1.778, 0), (-1.016, 0.508), (-1.016, -0.508), (-1.778, 0)], fill="outline"),
    _pl([(0, 1.778), (1.524, 1.778), (1.524, -1.778), (0, -1.778)]),
    _pl([(0.889, -0.381), (2.159, -0.381), (1.524, 0.508), (0.889, -0.381)], fill="outline"),
    _pl([(0.889, 0.508), (2.159, 0.508)]),
]
defsym("NMOS", "Q",
       [("1", "S", 0, -5.08, 90, 2.54, False), ("2", "S", 0, -5.08, 90, 2.54, True),
        ("3", "S", 0, -5.08, 90, 2.54, True), ("4", "G", -5.08, 0, 0, 2.54, False),
        ("5", "D", 0, 5.08, 270, 2.54, False)],
       _mos, ref_at=(3.81, 1.27), val_at=(3.81, -1.27))
for _nm, (_g, _d, _s) in {"NMOS_SOT23": ("1", "3", "2"), "NMOS_TO263": ("1", "2", "3")}.items():
    defsym(_nm, "Q", [(_s, "S", 0, -5.08, 90, 2.54, False), (_g, "G", -5.08, 0, 0, 2.54, False),
                      (_d, "D", 0, 5.08, 270, 2.54, False)], _mos, ref_at=(3.81, 1.27), val_at=(3.81, -1.27))
# 取付穴 (電気的接続なし)
defsym("MH", "H", [], [_circ(0, 0, 1.27), _circ(0, 0, 0.635)], ref_at=(2.54, 0.635), val_at=(2.54, -1.27))
defsym("SW", "SW", [("1", "~", -5.08, 0, 0, 2.54, False), ("2", "~", 5.08, 0, 180, 2.54, False)],
       [_circ(-2.032, 0, 0.508), _circ(2.032, 0, 0.508), _pl([(-2.032, 1.27), (2.032, 1.27)]),
        _pl([(0, 1.27), (0, 2.54)])], ref_at=(0, 3.81), val_at=(0, -2.54))
defsym("SJ2", "JP", [("1", "~", -3.81, 0, 0, 2.54, False), ("2", "~", 3.81, 0, 180, 2.54, False)],
       [_rect(-1.27, -1.016, -0.254, 1.016, fill="outline"), _rect(0.254, -1.016, 1.27, 1.016, fill="outline")],
       ref_at=(0, 2.54), val_at=(0, -2.54))
# 3 端子はんだジャンパ (1-2 が出荷時ブリッジ, 2 が共通)
defsym("SJ3", "JP", [("1", "~", -5.08, 0, 0, 2.54, False), ("2", "~", 0, -3.81, 90, 2.54, False),
                     ("3", "~", 5.08, 0, 180, 2.54, False)],
       [_rect(-2.286, -1.016, -1.27, 1.016, fill="outline"), _rect(-0.508, -1.016, 0.508, 1.016, fill="outline"),
        _rect(1.27, -1.016, 2.286, 1.016, fill="outline"), _pl([(-1.27, 0), (-0.508, 0)], 0.508)],
       ref_at=(0, 2.54), val_at=(0, 4.2))
# 丸端子 (リング端子) 用のネジ端子 1 極
defsym("TERM1", "J", [("1", "~", -5.08, 0, 0, 2.54, False)],
       [_rect(-2.54, -1.524, 2.54, 1.524, fill="background"), _circ(0.508, 0, 0.889)], ref_at=(0, 2.54), val_at=(0, -2.54))
defsym("TP", "TP", [("1", "~", 0, -2.54, 90, 1.27, False)], [_circ(0, 0, 1.27)],
       ref_at=(1.905, 1.27), val_at=(1.905, -1.27))
defsym("REG3", "U",
       [("3", "IN", -7.62, 0, 0, 2.54, False), ("1", "OUT", 7.62, 0, 180, 2.54, False),
        ("2", "GND", 0, -5.08, 90, 2.54, False)],
       [_rect(-5.08, 2.54, 5.08, -2.54, fill="background")], show_pin_names=True,
       ref_at=(-5.08, 3.81), val_at=(0, 3.81))


def conn_sym(n, prefix="J"):
    pins = [(str(i + 1), f"P{i + 1}", -5.08, -2.54 * i, 0, 3.81, False) for i in range(n)]
    gfx = [_rect(-1.27, 1.27, 1.27, -2.54 * (n - 1) - 1.27, fill="background")]
    for i in range(n):
        gfx.append(_rect(-1.27, -2.54 * i + 0.127, -0.508, -2.54 * i - 0.127))
    defsym(f"CONN{n}", prefix, pins, gfx, show_pin_numbers=True, ref_at=(0, 2.54), val_at=(0, 5.08))


for _n in (2, 3, 4, 5, 8, 21):
    conn_sym(_n)


def conn2_sym(rows, prefix="J"):
    """2 列ピンヘッダ (KiCad 2xNN と同じ番号: 奇数=左列, 偶数=右列)."""
    pins = []
    for r in range(rows):
        pins.append((str(2 * r + 1), f"P{2 * r + 1}", -7.62, -2.54 * r, 0, 3.81, False))
        pins.append((str(2 * r + 2), f"P{2 * r + 2}", 7.62, -2.54 * r, 180, 3.81, False))
    gfx = [_rect(-3.81, 1.27, 3.81, -2.54 * (rows - 1) - 1.27, fill="background")]
    defsym(f"CONN2x{rows}", prefix, pins, gfx, show_pin_numbers=True, ref_at=(0, 3.81), val_at=(0, 6.35))


for _n in (4, 5, 6, 8, 11):
    conn2_sym(_n)

# CH32M030C8U7 (QFN48 5x5mm / 0.35mm ピッチ) — データシート V1.2 表 2-1 の QFN48 列。
# 裏面パッド (DS ではピン番号 0) は KiCad の慣例に合わせて "49" とする。機能別に左右へ配置。
MCU_L = [("34", "VHV"), ("26", "VDD8"), ("33", "VDD33"), ("49", "GND(EP)"),
         ("37", "PA2/CC3/A15 (SWCLK)"), ("38", "PA3/SWDIO/CC4/A16"),
         ("35", "PA0/CC1R/A13"), ("36", "PA1/CC2R/A14"), ("39", "PB0/UDP/A11"), ("40", "PB1/UDM/A12"),
         ("8", "PB5/XI/A3"), ("9", "PB6/XO/A4"), ("27", "PC0/RST/T1C4"),
         ("28", "PC1/UART_TX"), ("29", "PC2/UART_RX_1"), ("30", "PC3"),
         ("31", "PC4/T1C2_3/SPI_MISO"), ("32", "PC5/HVIO"),
         ("3", "PA14/I2C_SDA_2/A9"), ("4", "PA15/I2C_SCL_2/A10"), ("2", "PA13/T1BKIN_1/A18"),
         ("43", "PA6/CM3N1/T2C2/ISINK1"), ("7", "PB4/V_DET(OVP)/A17"), ("6", "PB3/CM3P3/A1"),
         ("5", "PB2/CM3N3/A0")]
MCU_R = [("46", "ISP1"), ("45", "PA8/ISN1/A7"), ("47", "PA10/ISP2"), ("48", "PA11/ISN2/A8"),
         ("41", "PA4/ISOURCE1/A5"), ("42", "PA5/CM3N0/T2C1/ISRC2/A6"), ("44", "PA7/CM3N2/T2C3/ISINK2/A2"),
         ("1", "PA12/QII1(OPA1)/A19"),
         ("13", "PB9/T1C1/HO0"), ("12", "VB0"), ("11", "VS0"), ("10", "PB8/T1C1N/LO0"),
         ("17", "PB11/T1C2/HO1"), ("16", "VB1"), ("15", "VS1"), ("14", "PB10/T1C2N/LO1"),
         ("21", "PB13/T1C3/T2C1_2/HO2"), ("20", "VB2"), ("19", "VS2"), ("18", "PB12/T1C3N/T2C1N_2/LO2"),
         ("25", "PB15/T2C2_2/HO3"), ("24", "VB3"), ("23", "VS3"), ("22", "PB14/T2C2N_2/LO3")]
assert len(MCU_L) == 25 and len(MCU_R) == 24
assert sorted(int(n) for n, _ in MCU_L + MCU_R) == list(range(1, 50))
_mh = 2.54 * 24
_mcu_pins = [(n, nm, -30.48, _mh / 2 - 2.54 * i, 0, 5.08, False) for i, (n, nm) in enumerate(MCU_L)]
_mcu_pins += [(n, nm, 30.48, _mh / 2 - 2.54 * i, 180, 5.08, False) for i, (n, nm) in enumerate(MCU_R)]
defsym("CH32M030C8U7", "U", _mcu_pins,
       [_rect(-25.4, _mh / 2 + 2.54, 25.4, -_mh / 2 - 2.54, fill="background")],
       show_pin_names=True, show_pin_numbers=True, ref_at=(-25.4, _mh / 2 + 6.35),
       val_at=(-25.4, _mh / 2 + 3.81))

# USB Type-C レセプタクル (USB2.0 16P)。同名ピンは同位置に重ね、片方を隠しピンにする。
_usb = []
for i, (nums, nm) in enumerate([(("A4", "A9", "B4", "B9"), "VBUS"), (("A5",), "CC1"), (("B5",), "CC2"),
                                (("A6", "B6"), "D+"), (("A7", "B7"), "D-"), (("A8",), "SBU1"),
                                (("B8",), "SBU2"), (("A1", "A12", "B1", "B12"), "GND"), (("S1",), "SHIELD")]):
    for k, n in enumerate(nums):
        _usb.append((n, nm, 10.16, 10.16 - 2.54 * i, 180, 2.54, k > 0))
defsym("USBC16", "J", _usb, [_rect(-7.62, 12.7, 7.62, -12.7, fill="background")],
       show_pin_names=True, show_pin_numbers=True, ref_at=(-7.62, 15.24), val_at=(-7.62, 13.97))
defsym("USBLC6", "U",
       [("1", "IO1", -10.16, 2.54, 0, 2.54, False), ("2", "GND", -10.16, 0, 0, 2.54, False),
        ("3", "IO2", -10.16, -2.54, 0, 2.54, False), ("6", "IO1", 10.16, 2.54, 180, 2.54, False),
        ("5", "VBUS", 10.16, 0, 180, 2.54, False), ("4", "IO2", 10.16, -2.54, 180, 2.54, False)],
       [_rect(-7.62, 5.08, 7.62, -5.08, fill="background")], show_pin_names=True,
       show_pin_numbers=True, ref_at=(-7.62, 7.62), val_at=(-7.62, 6.35))
# 理想ダイオードコントローラ LM74700-Q1 (SOT-23-6, KiCad 公式シンボルと同じピン番号)
defsym("LM74700", "U",
       [("6", "ANODE", -10.16, 2.54, 0, 2.54, False), ("3", "EN", -10.16, 0, 0, 2.54, False),
        ("1", "VCAP", -10.16, -2.54, 0, 2.54, False), ("4", "CATHODE", 10.16, 2.54, 180, 2.54, False),
        ("5", "GATE", 10.16, 0, 180, 2.54, False), ("2", "GND", 0, -7.62, 90, 2.54, False)],
       [_rect(-7.62, 5.08, 7.62, -5.08, fill="background")], show_pin_names=True,
       show_pin_numbers=True, ref_at=(-7.62, 9.4), val_at=(-7.62, 6.6))
# 4 端子水晶 (1-3 が振動子, 2-4 がケース GND)
defsym("XTAL4", "Y",
       [("1", "1", -5.08, 0, 0, 2.54, False), ("3", "3", 5.08, 0, 180, 2.54, False),
        ("2", "GND", 0, -5.08, 90, 3.048, False), ("4", "GND", 0, -5.08, 90, 3.048, True)],
       [_rect(-1.016, -1.778, 1.016, 1.778), _pl([(-2.032, -1.27), (-2.032, 1.27)]),
        _pl([(2.032, -1.27), (2.032, 1.27)]), _pl([(-2.54, 0), (-2.032, 0)]), _pl([(2.54, 0), (2.032, 0)])],
       ref_at=(0, 3.81), val_at=(0, -3.81))
defsym("D_SCH", "D", [("1", "K", -3.81, 0, 0, 2.54, False), ("2", "A", 3.81, 0, 180, 2.54, False)],
       [_pl([(1.27, 1.27), (1.27, -1.27), (-1.27, 0), (1.27, 1.27)]),
        _pl([(-1.778, 0.762), (-1.778, 1.27), (-1.27, 1.27), (-1.27, -1.27), (-0.762, -1.27), (-0.762, -0.762)])])


def lib_symbols_sexpr(used):
    out = ["(lib_symbols"]
    for name in sorted(used):
        s = SYMS[name]
        pn = "" if s["spn"] else "(pin_names hide) "
        pnum = "" if s["spnum"] else "(pin_numbers hide) "
        if s["spn"]:
            pn = "(pin_names (offset 0.508)) "
        out.append(f'(symbol "mdrv:{name}" {pnum}{pn}(in_bom yes) (on_board yes)')
        out.append(f'(property "Reference" "{s["prefix"]}" (at 0 0 0) (effects (font (size 1.27 1.27))))')
        out.append(f'(property "Value" "{name}" (at 0 0 0) (effects (font (size 1.27 1.27))))')
        out.append('(property "Footprint" "" (at 0 0 0) (effects (font (size 1.27 1.27)) hide))')
        out.append('(property "Datasheet" "~" (at 0 0 0) (effects (font (size 1.27 1.27)) hide))')
        out.append(f'(symbol "{name}_0_1" ' + " ".join(s["gfx"]) + ")")
        pins = []
        for num, nm, x, y, a, ln, hid in s["pins"]:
            h = " hide" if hid else ""
            pins.append(f'(pin passive line (at {x:g} {y:g} {a}) (length {ln:g}){h} '
                        f'(name "{nm}" (effects (font (size 1.016 1.016)))) '
                        f'(number "{num}" (effects (font (size 1.016 1.016)))))')
        out.append(f'(symbol "{name}_1_1" ' + " ".join(pins) + ")")
        out.append(")")
    out.append(")")
    return "\n".join(out)


# ---------------------------------------------------------------------------
# 部品・シート
# ---------------------------------------------------------------------------
FP = {
    # 受動部品: 1005 / 1608 を基本とし, 耐圧・電流の都合で必要なものだけ大きくする (docs/design.md 表)
    "R1005": "Resistor_SMD:R_0402_1005Metric",
    "R1608": "Resistor_SMD:R_0603_1608Metric",
    "R2012": "Resistor_SMD:R_0805_2012Metric",
    "R1206": "Resistor_SMD:R_1206_3216Metric",
    "R2512": "Resistor_SMD:R_2512_6332Metric",
    "C1005": "Capacitor_SMD:C_0402_1005Metric",
    "C1608": "Capacitor_SMD:C_0603_1608Metric",
    "C2012": "Capacitor_SMD:C_0805_2012Metric",
    "CP6": "Capacitor_THT:CP_Radial_D6.3mm_P2.50mm",
    "CP8": "Capacitor_THT:CP_Radial_D8.0mm_P3.50mm",
    "TSON": "Package_SO:Vishay_PowerPAK_1212-8_Single",
    "TO263": "Package_TO_SOT_SMD:TO-263-2",
    "SOT23": "Package_TO_SOT_SMD:SOT-23",
    "QFN48": "CH32M030DS0_QFN48:CH32M030DS0_QFN48",
    "USBC": "Connector_USB:USB_C_Receptacle_GCT_USB4105-xx-A_16P_TopMnt_Horizontal",
    "SOT236": "Package_TO_SOT_SMD:SOT-23-6",
    "SOT89": "Package_TO_SOT_SMD:SOT-89-3",
    "SMA": "Diode_SMD:D_SMA",
    "SMB": "Diode_SMD:D_SMB",
    "SOD123": "Diode_SMD:D_SOD-123",
    "SOD123F": "Diode_SMD:D_SOD-123F",
    "LED1608": "LED_SMD:LED_0603_1608Metric",
    "NANO2": "mPB:Fuse_Littelfuse_NANO2_2410",
    "FUSE1812": "Fuse:Fuse_1812_4532Metric",
    "PTC1206": "Fuse:Fuse_1206_3216Metric",
    "XTAL3225": "Crystal:Crystal_SMD_3225-4Pin_3.2x2.5mm",
    "SW": "Button_Switch_SMD:SW_SPST_B3U-1000P",
    "HDR2": "Connector_PinHeader_2.54mm:PinHeader_1x02_P2.54mm_Vertical",
    "HDR3": "Connector_PinHeader_2.54mm:PinHeader_1x03_P2.54mm_Vertical",
    "HDR4": "Connector_PinHeader_2.54mm:PinHeader_1x04_P2.54mm_Vertical",
    "HDR5": "Connector_PinHeader_2.54mm:PinHeader_1x05_P2.54mm_Vertical",
    "HDR8": "Connector_PinHeader_2.54mm:PinHeader_1x08_P2.54mm_Vertical",
    "HDR2x4": "Connector_PinHeader_2.54mm:PinHeader_2x04_P2.54mm_Vertical",
    "HDR2x5": "Connector_PinHeader_2.54mm:PinHeader_2x05_P2.54mm_Vertical",
    "HDR2x11": "Connector_PinHeader_2.54mm:PinHeader_2x11_P2.54mm_Vertical",
    "SOCK2x5": "Connector_PinSocket_2.54mm:PinSocket_2x05_P2.54mm_Vertical",
    "SOCK2x11": "Connector_PinSocket_2.54mm:PinSocket_2x11_P2.54mm_Vertical",
    "HDR1x21": "Connector_PinHeader_2.54mm:PinHeader_1x21_P2.54mm_Vertical",
    "SOCK1x21": "Connector_PinSocket_2.54mm:PinSocket_1x21_P2.54mm_Vertical",
    "HDR2x6": "Connector_PinHeader_2.54mm:PinHeader_2x06_P2.54mm_Vertical",
    "HDR2x8": "Connector_PinHeader_2.54mm:PinHeader_2x08_P2.54mm_Vertical",
    "SJ3": "Jumper:SolderJumper-3_P1.3mm_Bridged12_RoundedPad1.0x1.5mm_NumberLabels",
    "LED1005": "LED_SMD:LED_0402_1005Metric",
    "C1206": "Capacitor_SMD:C_1206_3216Metric",
    "CPE8x6": "Capacitor_SMD:CP_Elec_8x6.2",
    "CPE6x6": "Capacitor_SMD:CP_Elec_6.3x5.9",
    "MH": "MountingHole:MountingHole_2.2mm_M2",
    "MH32": "MountingHole:MountingHole_3.2mm_M3",
    "REDCUBE_M3": "TerminalBlock_Wuerth:Wuerth_REDCUBE-THR_WP-THRBU_74650073_THR",
}


class Sheet:
    def __init__(self, key, title, page):
        self.key, self.title, self.page = key, title, page
        self.parts, self.texts, self.boxes = [], [], []
        self.wires, self.junctions, self.labels = [], [], []

    def add(self, sym, ref, value, x, y, rot=0, nets=None, fp="", dnp=False, mpn="", wired=()):
        """wired: 手配線するピン番号 (スタブ/ラベルを自動生成しない)。"""
        nets = nets or {}
        pins = {p[0] for p in SYMS[sym]["pins"] if not p[6]}
        assert set(nets) == pins, f"{ref}: pins {sorted(pins)} vs nets {sorted(nets)}"
        assert fp in FP or ":" in fp or not pins, f"{ref}: unknown footprint {fp}"
        self.parts.append(dict(sym=sym, ref=ref, value=value, x=x, y=y, rot=rot, nets=nets,
                               fp=FP.get(fp, fp), dnp=dnp, mpn=mpn, wired=set(wired)))
        return self.parts[-1]

    def pin(self, part, num):
        """部品ピンの回路図座標."""
        q = next(q for q in SYMS[part["sym"]]["pins"] if q[0] == num)
        return xform(part["x"], part["y"], part["rot"], q[2], q[3])

    def wire(self, *pts):
        for a, b in zip(pts, pts[1:]):
            self.wires.append((a, b))

    def junction(self, x, y):
        self.junctions.append((x, y))

    def label(self, net, x, y, ang):
        """(x, y) から ang 方向へ 2.54mm のスタブを引き、その先にラベルを置く."""
        d = {0: (2.54, 0), 180: (-2.54, 0), 90: (0, -2.54), 270: (0, 2.54)}[ang]
        e = (x + d[0], y + d[1])
        self.wires.append(((x, y), e))
        self.labels.append((net, e[0], e[1], ang))

    def text(self, s, x, y, size=1.8):
        self.texts.append((s, x, y, size))

    def box(self, x0, y0, x1, y1, title):
        self.boxes.append((x0, y0, x1, y1, title))


def xform(px, py, rot, lx, ly):
    """lib 座標 -> 回路図座標 (y 下向き, rot は画面上の反時計回り)."""
    x, y = lx, -ly
    r = math.radians(rot)
    c, s = round(math.cos(r)), round(math.sin(r))
    return px + x * c + y * s, py - x * s + y * c


OUTWARD = {0: (-1, 0), 180: (1, 0), 90: (0, -1), 270: (0, 1)}  # lib 座標での外向き




# ---------------------------------------------------------------------------
# 部品定数 (コンデンサは耐圧・DC バイアス・入手性から現実的なサイズを選ぶ)
#   1005: 0.1uF/50V, 1uF/25V, 10nF・1nF (X7R), 30pF・1nF・2.2nF (C0G) — いずれも大量流通品
#   1608: 1uF/50V, 2.2uF/25V, 4.7uF/16V, 4.7nF/100V
#   2012: 10uF/25V (VDD8 10V 時の実効容量確保)   1206: 10uF/50V (VHV・VBUS)
# ---------------------------------------------------------------------------
C_100N = ("0.1uF/50V", "C1005", "Murata GRM155R71H104KE14D (X7R 1005)")
C_1U25 = ("1uF/25V", "C1005", "Murata GRM155R61E105KA12D (X5R 1005)")
C_1U50 = ("1uF/50V", "C1608", "Murata GRM188R61H105KAALD (X5R 1608)")
C_2U2 = ("2.2uF/25V", "C1608", "Murata GRM188R61E225KA12D (X5R 1608)")
C_4U7 = ("4.7uF/16V", "C1608", "Samsung CL10A475KO8NNNC (X5R 1608)")
C_10U25 = ("10uF/25V", "C2012", "Murata GRM21BR61E106KA73L (X5R 2012)")
C_10U50 = ("10uF/50V", "C1206", "Murata GRM31CR61H106KA12L (X5R 1206)")
# レッグの VBUS-SRC 容量 (子基板の下面, MOSFET の横)。A/C は MOSFET より低い 0.85mm 厚にして, ヒートシンクが FET に当たるようにする
C_10U25_LP = ("10uF/25V", "C2012", "Murata GRM219R61E106KA12D (X5R 0805, 厚さ 0.85mm)")
C_10N = ("10nF/50V", "C1005", "Murata GRM155R71H103KA88D (X7R 1005)")
C_1N = ("1nF/50V", "C1005", "Murata GRM155R71H102KA01D (X7R 1005)")
C_1N_C0G = ("1nF C0G", "C1005", "Murata GRM1555C1H102JA01D (C0G 1005)")
C_2N2_C0G = ("2.2nF C0G", "C1005", "Murata GRM1555C1H222JA01D (C0G 1005)")
C_30P = ("30pF C0G", "C1005", "Murata GRM1555C1H300JA01D (C0G 1005)")
C_4N7_100 = ("4.7nF/100V", "C1608", "Samsung CL10B472KC8NNNC (X7R 100V 1608)")


def cap(sh, ref, spec, x, y, n1, n2, rot=90, **kw):
    val, fp, mpn = spec
    return sh.add("C", ref, val, x, y, rot=rot, nets={"1": n1, "2": n2}, fp=fp, mpn=mpn, **kw)


def res(sh, ref, val, x, y, n1, n2, rot=90, fp="R1005", **kw):
    return sh.add("R", ref, val, x, y, rot=rot, nets={"1": n1, "2": n2}, fp=fp, **kw)


# ---------------------------------------------------------------------------
# モジュールの端子 (DIP 型: 2.54mm ピッチ 21 ピン x 2 列, 列間 17.78mm = 0.7")
#   ブレッドボードに直接挿せる / パワー段子基板のピンソケット (左右対称) に挿せる。
#   左列 J1 = 電源・アナログ・センサ, 右列 J2 = ゲート駆動・通信。子基板は同じ番号で受ける。
# ---------------------------------------------------------------------------
# 並びは QFN の各辺のピン順に合わせ, 引き出し配線が交差しないようにした (上辺の右側 → J2 上部,
# 上辺の左側 → J1 上部, 右辺のゲート → J2 中央, 下辺の右寄り → J2 下部, 左辺のアナログ → J1 下部)。
EDGE_L = ["USB_VBUS", "USB_VBUS", "PD_PWR_EN", "GPIO_PC4", "GPIO_PC5", "+3V3", "+5V", "SWDIO", "VBUS",
          "NTC", "BEMF_U", "BEMF_V", "BEMF_W", "HALL_A_IN", "HALL_B_IN", "HALL_C_IN",
          "ISA_SEL", "ISH", "ISB_SEL", "TACH_IN", "GND"]
EDGE_R = ["GND", "UART_RX", "UART_TX", "nRST",
          "HO3", "SW3", "LO3", "HO2", "SW2", "LO2", "HO1", "SW1", "LO1", "HO0", "SW0", "LO0",
          "VBUS_SNS", "I2C_SCL", "I2C_SDA", "nFAULT_IN", "GND"]
assert len(EDGE_L) == 21 and len(EDGE_R) == 21
PINMAP_L = {str(i + 1): n for i, n in enumerate(EDGE_L)}
PINMAP_R = {str(i + 1): n for i, n in enumerate(EDGE_R)}


class Project:
    def __init__(self, name, subdir, title, notes):
        self.name, self.subdir, self.title, self.notes = name, subdir, title, notes
        self.sheets = []

    def sheet(self, key, title):
        sh = Sheet(key, title, len(self.sheets) + 2)
        self.sheets.append(sh)
        return sh


PROJECTS = []
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

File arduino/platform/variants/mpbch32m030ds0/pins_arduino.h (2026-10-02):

/*
 * pins_arduino.h — mPBCH32M030DS0 の端子番号 (番号 = ポート × 16 + ビット: PA0 = 0, PB0 = 16, PC0 = 32)
 * モジュールの端子 (J1 / J2) との対応はリポジトリの README を参照。
 */
#ifndef PINS_ARDUINO_H
#define PINS_ARDUINO_H

enum {
    PA0 = 0, PA1, PA2, PA3, PA4, PA5, PA6, PA7, PA8, PA9, PA10, PA11, PA12, PA13, PA14, PA15,
    PB0 = 16, PB1, PB2, PB3, PB4, PB5, PB6, PB7, PB8, PB9, PB10, PB11, PB12, PB13, PB14, PB15,
    PC0 = 32, PC1, PC2, PC3, PC4, PC5, PC6, PC7
};

#define LED_BUILTIN     PC4     /* 状態 LED D3 (Low で点灯) — USER ボタン SW2 と共用 */
#define BUTTON_BUILTIN  PC4     /* 押すと Low */
#define PIN_HALL_A      PA5     /* J1-14 (JP2 = 2-3 で外部入力) */
#define PIN_HALL_C      PA6     /* J1-16 (JP4 = 2-3) */
#define PIN_HALL_B      PA7     /* JP3 = 2-3 */
#define PIN_UART_RX     PC2     /* J2-2 */
#define PIN_UART_TX     PC1     /* J2-3 */
#define PIN_SDA         PA14    /* J2-19 */
#define PIN_SCL         PA15    /* J2-18 */
#define PIN_HV_IO       PC5     /* High = VHV (軽負荷のプッシュプル) */

#endif

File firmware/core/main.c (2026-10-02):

/*
 * mPBCH32M030DS0 アプリケーション テンプレート (Arduino 風: setup() / loop())
 *
 * このファイルは「書き込み要求に応える仕組み」を持つ main() で、ユーザーのコードは
 * sketch.c の setup() / loop() に書く。0x08005000 にリンクされ、ブートローダから起動される。
 *
 *  - USB: WCH IAP 互換のベンダーインターフェース (VID 1A86 / PID 55E0, bcdDevice 0xA001)
 *         ホストが CMD_JUMP_IAP (0x84) を送ると、要求フラグを書いてリセット → ブートローダへ。
 *         tools/mpb_upload.py はこれを自動で行う (ESP32 / Arduino の自動リセットと同じ感覚)。
 *  - UART (PC1/PC2, 460800bps) でも同じコマンドを受け付ける (MPB_UART_BOOT=0 で無効化)。
 *
 * 原型: WCH CH32M030 EVT "UART_USB_IAP/CH32M030_APP" (Copyright (c) 2021 Nanjing Qinheng
 * Microelectronics Co., Ltd. — WCH 製 MCU で使用する場合に限り利用可)
 * Modified 2026 by ghostinkoma.
 */
#include "ch32m030_usbfs_device.h"
#include "debug.h"
#include "iap.h"
#include "board.h"
#include "mpb.h"

#ifndef MPB_UART_BOOT
#define MPB_UART_BOOT 1
#endif

void setup(void);
void loop(void);
/* RTOS (Arduino の FreeRTOS ライブラリ) が定義する: setup() の後で loop() をタスクにしてスケジューラを開始する */
void Mpb_Rtos_AfterSetup(void) __attribute__((weak));
void Mpb_Uart_TxIrq(void);

void USART1_IRQHandler(void) MPB_IRQ;

/* ブート要求フラグが書かれていたらリセットしてブートローダへ。
 * 通常は main の loop で毎回呼ぶ。RTOS で loop() に戻らないスケッチはタスクから Mpb_Core_Service() を呼ぶ */
void Mpb_Core_Service(void)
{
    Mpb_Wdt_Feed();                 /* ここまで来た = loop() (またはこれを呼ぶタスク) は動いている */
    if (*(vu32 *)CalAddr == CheckNum)
    {
        Mpb_Gates_Off();            /* リセット前に全 FET OFF */
        Delay_Ms(10);
        NVIC_SystemReset();
        while (1)
            ;
    }
}

#if MPB_UART_BOOT
static void USART1_IT_CFG(void)
{
    USART_ITConfig(USART1, USART_IT_RXNE, ENABLE);
    NVIC_SetPriority(USART1_IRQn, 1 << 6);
    NVIC_EnableIRQ(USART1_IRQn);
    USART_Cmd(USART1, ENABLE);
}
#endif

/* 送信割込み (TXE) のフック: lib/mpb_log.c が使う */
__attribute__((weak)) void Mpb_Uart_TxIrq(void)
{
    USART_ITConfig(USART1, USART_IT_TXE, DISABLE);
}

void USART1_IRQHandler(void)
{
#if MPB_UART_BOOT
    if (USART_GetFlagStatus(USART1, USART_FLAG_RXNE) != RESET)
    {
        UART_Rx_Deal();
    }
#endif
    if ((USART1->CTLR1 & UART_CTLR1_TXEIE) && USART_GetFlagStatus(USART1, USART_FLAG_TXE) != RESET)
    {
        Mpb_Uart_TxIrq();
    }
}

int main(void)
{
    Mpb_Gates_Off();                /* 最初に全 FET OFF を確定 (リセット直後もハード的に OFF だが, 能動的に Low にする) */
    Mpb_Wdt_ReadResetCause();
    SystemCoreClockUpdate();
    Delay_Init();
#if MPB_WDT_MS
    Mpb_Wdt_Start(MPB_WDT_SETUP_MS);   /* setup() の間は長め */
#endif

    /* USB ベンダーインターフェース (書き込み要求の受付) */
    USBFS_RCC_Init();
    USBFS_Device_Init(ENABLE);
#if MPB_UART_BOOT
    USART1_CFG(MPB_UART_BAUD);
    USART1_IT_CFG();
#endif

#ifdef ARDUINO
    {
        /* Arduino (C++): 大域オブジェクトのコンストラクタを呼ぶ (スタートアップは呼ばないので) */
        extern void (*__init_array_start[])(void);
        extern void (*__init_array_end[])(void);
        for (void (**f)(void) = __init_array_start; f < __init_array_end; f++) (*f)();
    }
    Mpb_Time_Init();                /* millis() / micros() を setup() の前から使えるように */
#endif
    setup();
#if MPB_WDT_MS
    Mpb_Wdt_SetLimit(MPB_WDT_MS);
#endif
    if (Mpb_Rtos_AfterSetup)
    {
        Mpb_Rtos_AfterSetup();      /* 戻らない */
    }
    while (1)
    {
        loop();
        Mpb_Core_Service();
    }
}

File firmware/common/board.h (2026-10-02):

/*
 * mPBCH32M030DS0 ボード定義 (ブートローダ / アプリ共通)
 * Copyright (c) 2026 ghostinkoma — LICENSE 参照
 */
#ifndef MPB_BOARD_H
#define MPB_BOARD_H

#include "ch32m030.h"

/* ---- フラッシュ配置 (64KB) --------------------------------------------------
 * 0x08000000 - 0x08004FFF : ブートローダ (20KB, WCH IAP 互換)
 * 0x08005000 - 0x0800FF7F : アプリケーション (44KB - 128B)
 * 0x0800FF80 - 0x0800FFFF : ブート要求フラグページ (末尾 4 バイトにマジック値)
 */
#define MPB_APP_ADDR        0x08005000u
#define MPB_APP_OFFSET      0x00005000u
#define MPB_FLAG_ADDR       (0x08010000u - 4u)
#define MPB_FLAG_MAGIC      0x5aa55aa5u

/* USB: WCH IAP 互換 (VID 0x1A86 / PID 0x55E0, ベンダークラス, EP2 バルク)
 * bcdDevice の上位バイトで区別する: 0xB0 = ブートローダ, 0xA0 = アプリ */
#define MPB_BCD_BOOTLOADER  0xB001
#define MPB_BCD_APP         0xA001

/* ---- ピン ---------------------------------------------------------------- */
/* USER/BOOT ボタン: PC4 (Low = 押下, 外部 10k プルアップ) */
#define MPB_BOOTKEY_PORT    GPIOC
#define MPB_BOOTKEY_PIN     GPIO_Pin_4
#define MPB_BOOTKEY_RCC     RCC_PB2Periph_GPIOC
/* 状態 LED: PC4 (USER/BOOT と共用, Low = 点灯)。+3V3 - LED - 1k - PC4 なのでオープンドレインで駆動する
 * (ボタン押下で Low になっても短絡しない) */
#define MPB_LED_PORT        GPIOC
#define MPB_LED_PIN         GPIO_Pin_4
#define MPB_LED_RCC         RCC_PB2Periph_GPIOC
#define MPB_LED_ON          Bit_RESET
#define MPB_LED_OFF         Bit_SET
/* USB-PD 給電パス許可: PC3 (High = U5 LM74700 有効, 外部 100k プルダウン) */
#define MPB_PDEN_PORT       GPIOC
#define MPB_PDEN_PIN        GPIO_Pin_3
/* UART: USART1 リマップ1 (TX = PC1, RX = PC2)。PC0 は RST ピン */
#define MPB_UART_REMAP      GPIO_PartialRemap1_USART1
#ifndef MPB_UART_BAUD
#define MPB_UART_BAUD       460800u       /* src/config.h で変えられる */
#endif

/* ---- 割り込み属性 --------------------------------------------------------
 * MounRiver (WCH GCC) では WCH 独自の高速割り込み、
 * 汎用 GCC (Ubuntu riscv64-unknown-elf / xPack) では標準の machine 割り込みを使う。 */
#ifdef USE_STD_IRQ_ATTR
#define MPB_IRQ __attribute__((interrupt("machine")))
#else
#define MPB_IRQ __attribute__((interrupt("WCH-Interrupt-fast")))
#endif

#endif /* MPB_BOARD_H */

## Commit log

2026-09-24 Initial commit: CH32M030C8U7 ユニバーサル・モータードライバ (回路図・ブートローダ・書込ツール)
    - hardware: KiCad 回路図 (トップ + 電源 / USB・水晶・リセット / MCU / パワー段 / I/O)
    - CH32M030C8U7 (QFN48 5x5mm) + TPN1R603PL x8, 3相 / DC x2 / ステッピング対応
    - USB-C (CC1R/CC2R = PA0/PA1, D+/D- = PB0/PB1), RESET (PC0), 8MHz 水晶 (PB5/PB6)
    - 電源 LED x3, ゲート確認 LED x8, シャント電流の ADC 計測 (OPA3/OPA4/IBUS)
    - GPIO 引き出し (J6), 端子台配置図 (docs/placement.svg)
    - gen_schematic.py から生成し kicad-cli ネットリストで 95/95 ネット一致を確認
    - 作業途中データ (hardwar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
    [bom.csv, bridge.kicad_sch, io.kicad_sch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]
2026-09-24 Rev 0.2: 内蔵機能 (電流源/シンク・USB-PD・OPA/CMP 全モード) の活用
    回路 (102/102 ネット一致):
    - USB-PD シンクでモーター電源を供給: F3 → U5 LM74700 + Q10 → VBUS (PC3 で許可),
    USB VBUS 監視 (PA2), SMAJ20A。USBLC6 の基準を +3V3 に変更 (VBUS 20V 対策)
    - J1 の逆接保護を U4 LM74700 + Q9 のハイサイド理想ダイオードに変更 (J1 / PD を安全に OR)
    - 3 相センシングを PA5/PA6/PA7 に集約 (W 相 PA12 → PA6): CMP3 内部仮想中性点 + TIM2 捕捉
    によるセンサレス BEMF 検出, TIM2 ホール XOR, ISOURCE2 結線診断を同じピンで利用
    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
    [bom.csv, bridge.kicad_sch, io.kicad_sch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]
2026-09-25 Rev 0.3: パワー段を子基板化 (A/B/C/D) し 2 層基板レイアウトを作成
    構成:
    - 主基板 (60x42mm, 2 層): 右 = CH32M030 / USB-C / GPIO・I2C・UART・SDI・HALL,
    左上 = 電源 (J1 → F1 → 理想ダイオード, USB-PD 経路), 左下 = 基板間コネクタ J9/J10 (裏面)
    - 子基板と裏面同士を背中合わせに重ねる (基板間 約5mm, 裏面部品は高さ 2mm 以下)。
    RESET / USER・BOOT / センシング選択は主基板 TOP、電流チャネル選択 JP5/JP7 は子基板 TOP
    - 子基板 A: TPN1R603PL (既存回路) / B: TKR74F04PB (24V 系, 66x66mm) /
    C: MTN2306AN3 (廉価版) / D: MOSFET なし (全信号をピンヘッダへ引き出し)
    -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
    [b2b.kicad_sch, bom.csv, breakout.kicad_sch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]
2026-09-26 Rev 0.4: DIP-42 MCU module + power boards A/B/C (KiCad 8)
    - MCU module: 20.32 x 53.34mm (8 x 21 grid), DIP-42 (0.6in rows), fits
    an 82 x 52mm breadboard. Headers can be fitted from either side;
    signal names on bottom silk. All LEDs (power, status, 8 gate LEDs) on
    the module top.
    - Power boards take the module in two 1x21 sockets (left/right
    symmetric mating). FETs/shunts on the heatsink side, no LEDs.
    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
    [b2b.kicad_sch, bom.csv, breakout.kicad_sch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]
2026-09-26 Rev 0.4: rework module pinout for routability, power boards regenerated
    - Module edge pin order follows the CH32M030 QFN48 pin sides so the
    breakout traces nest instead of crossing (J1: USB_VBUS, PD_PWR_EN,
    PC4/PC5, +3V3, +5V, SWDIO, VBUS, NTC, BEMF, HALL, ISx, TACH;
    J2: RX/TX, nRST, gate drive HO3..LO0, VBUS_SNS, I2C, nFAULT).
    - Module: area under the QFN kept for fan-out (filters and the VHV/USB
    diode block moved away, gate LEDs right-aligned to J2).
    - Power boards A/B/C re-placed for the new pinout (VBUS divider next to
    J2 VBUS_SNS, LM74700 next to its FET) and re-routed: all three at
    0 unconnected / 0 electrical DRC errors.
    - Layout tooling: DRC via kicad-cli in a separate pr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
    [io.kicad_sch, mPBCH32M030DS0.kicad_pcb, mPBCH32M030DS0_PWR_A.kicad_pcb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]
2026-09-26 docs: record remaining manual routing on the MCU module
    List the 22 unconnected module nets left by the automatic router and
    how to finish them in KiCad; note the 9-grid (22.86mm) experiment that
    reduced them to 10.
    Claude-Session: https://claude.ai/code/session_01LENFjjhDfYjJZV1NWhB9uV
2026-09-26 Rev 0.4: add 9-grid (22.86mm) module and power boards, no-pour boards
    - 9-grid variant (MPB_W9=1): module 22.86 x 53.34mm with 0.7in header
    rows, power boards A/C 22.86 x 70.74mm and B 43.18 x 66.94mm, output
    to hardware/w9/ (fab data in hardware/fab/w9/, images in docs/pcb/w9/).
    Power boards A/B/C: 0 unconnected / 0 electrical DRC errors.
    Module: 8 unconnected left for manual routing (8-grid: 22).
    - No-pour boards for manual routing (hardware/w8_nopour/,
    hardware/w9_nopour/): routed tracks and vias kept, GND pours, grown
    power copper and stitching vias removed (gen_pcb.py nopour).
    - gen_pcb.py: variant-aware output folders and inner placement range,
    horizontal scale/offset kno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
    [bom.csv, bridge.kicad_sch, io.kicad_sch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]
2026-09-26 9マス版 MCU モジュールの配線を完成 (未接続 0)
    - 水晶 Y1 と C131/C132 を QFN 下辺の XI/XO (8/9 番ピン) 直下の裏面へ移動し、
    下辺ピン 1〜7 の引き出しを空けて再配線 (9 マス版のみ)
    - DRC: 未接続 0 / 電気的エラー 0 (シルク警告のみ)
    - ベタなし版 (w9_nopour)、製造データ、図、DRC まとめを再生成
    - 手配線補助ツール hand_route.py / negot_route.py を追加
    - README / stacking.md の状況を更新
    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
    [mPBCH32M030DS0.kicad_pcb]
2026-09-27 8マス版 MCU モジュールの配線を完成 (未接続 0)
    - 水晶 Y1 と C131/C132 を XI/XO 直下の裏面へ移す配置を 8 マス版にも適用
    - 8 マス版モジュールのみ線幅・間隙 0.10mm / ビア 0.5mm (穴 0.25mm) に詰める
    (0.127mm では 5 通りの試行とも未接続 19〜27 が残ったため)。MPB_RULE / MPB_VIA で上書き可
    - ベタなし版 (w8_nopour)、製造データ、図、DRC まとめを再生成
    - README / stacking.md を更新 (両版とも配線完了)
    Claude-Session: https://claude.ai/code/session_01LENFjjhDfYjJZV1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
    [mPBCH32M030DS0.kicad_pcb]
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2026-09-27 9マス版に一本化 (8マス版を削除)
    - 8 マス版 (20.32mm) は JLCPCB の 2 層標準 0.127mm で配線しきれないため削除
    - 9 マス版 (22.86mm, 端子列 0.7in) を hardware/ 直下・hardware/daughter/・hardware/fab/・docs/pcb/ へ移動
    - ベタなし版は hardware/nopour/ (図は docs/pcb/nopour/)
    - gen_pcb.py から MPB_W9 の切り替えを外し 9 マス固定に。既定ルールは 0.127mm / ビア 0.6/0.3
    (再生成した配置が確定済みの 4 基板と一致することを確認)
    - 回路図の注記 (外形・列間) を 22.86mm / 17.78mm に更新し PDF を再出力
    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
    [bom.csv, bridge.kicad_sch, io.kicad_sch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]
2026-09-27 ベタを基板端から 1.0mm 後退し、ミシン目の発注用パネルを追加
    - pcblib.ZONE_EDGE (既定 1.0mm) を追加。GND ベタ・大電流の太らせたベタを基板端から 1.0mm 離す
    - gen_pcb.py zone_edge: 配線済みの 4 基板のベタだけを塗り直し (配線はそのまま)。全基板 未接続 0 / 電気的エラー 0
    - gen_panel.py: モジュール + 子基板 A/B/C を 97.9 x 95.6mm に面付け (2mm 溝 + マウスバイト)。
    タブは基板端 1.2mm 以内に銅の無い区間だけに置く。パネル DRC: 未接続 0 / 電気的エラー 0
    - 製造データ hardware/fab/mPBCH32M030DS0_panel.zip (銅・レジスト・シルク・ペースト・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
    [mPBCH32M030DS0.kicad_pcb, mPBCH32M030DS0_PWR_A.kicad_pcb, mPBCH32M030DS0_PWR_B.kicad_pcb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]
2026-09-28 モジュールの nFAULT フィルタ・USB GND 強化, 3D モデルと干渉チェック, 電流容量チェックの道具
    - nFAULT (TIM1 BKIN) に 1nF (C120) を追加。470Ω と 0.47µs。CH32M030 の TIM1 には BKIN の
    デジタルフィルタが無いため, ハードの RC で誤停止を防ぐ (配線済みの基板へ追加して迷路配線で接続)
    - USB-C (J8) の GND パッド脇に GND ビアを追加し, 下面の GND ベタへ直結 (5A 帰路の細い箇所を解消)
    - USB-PD の要求電流を min(want_mA, 3000mA) に頭打ち (J8 の VBUS パッド口元の銅幅で決まる上限)
    - KiCad 8 標準に無い 3D モデルを作成 (QFN48 0.35mm, TSON Advance, 1812 / N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
    [bom.csv, io.kicad_sch, mPBCH32M030DS0.kicad_pcb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]
2026-09-28 子基板 A/C: 電源の銅箔を配線前に置く再レイアウト (A 約4A/相, C 3A)
    - レッグを LS/HS の縦ブロックにし, 下面 = ISH の背骨 + SRC/VBUS/SW の島,
    上面 = VBUS の帯と各相 SW の階段状の帯 (J4 は 180° 回転: OUT3 が上)
    - 固定ベタは DSN では keepout (縁 0.3mm は同ネットの取り付き用) + via_keepout にして
    自動配線がベタを削らないようにした。2 段配線 (MPB_TWO_PHASE) も用意
    - A: ゲート抵抗 (0805) の電極間を SW/GL が抜ける配置 (J2 の並びと FET のゲート位置の上下逆を解消)
    - A/C: バルク容量は ISH 戻り (VBUS-ISH), USB 側 TVS (D9) は省略, NTC は下側へ
    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
    [bom.csv, bridge.kicad_sch, mPBCH32M030DS0_PWR_A.kicad_pcb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]
2026-09-28 子基板 A/C: 電源ベタにはんだ盛り用のレジスト開口, JP5 の向きを修正
    - 配線前に置く電源ベタ (VBUS/ISH/VIN/VIN_F/GND/SW*/SRC*) の上のレジストを開ける
    (ベタの塗りを 0.25mm 内側に縮めた形。銅の縁と他ネットの間はレジストを残してブリッジを防ぐ)
    - JP5 を 180° 回して 1 番 (SRC1) をレッグ 1 側へ。SRC2 が ISH の背骨 (下面) を横切っていたのを解消
    (A の ISH レッグ 2/3: 4.5A → 7.9A)
    - 電流容量チェック (tools/power_check): レジスト開口のはんだ厚 (MPB_SOLDER_T) を銅の厚みに換算して解く
    - A: はんだ 0.3mm 盛りで全経路 5A 以上 (最小 SW 5.9A,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
    [mPBCH32M030DS0_PWR_A.kicad_pcb, mPBCH32M030DS0_PWR_C.kicad_pcb]
2026-09-28 面付けパネルを A/C 74.9mm に合わせて更新, 製造データと資料を最新の A/C に
    - gen_panel.py: A/C の長さ 70.74 → 74.9mm (パネル 97.9 × 99.8mm)。タブを銅の無い区間へ移動
    (A の右辺は J2 沿いの GND 配線があるため A↔C / C↔B のタブは下寄り)
    - 各基板の製造データ (hardware/fab/*.zip) と DRC 集計を再生成
    - README / stacking.md: A/C の寸法・電流の目安 (A 約 5A/相 はんだ盛り時, C 約 3A/相) とレイアウトの説明,
    電源ベタのはんだ盛りの注意 (低温はんだ不可, 下面は盛り 0.3〜0.5mm 以下), J3/J4 の向き, D9 を外した理由
    - B はレイアウト見直し中と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
    [mPBCH32M030DS0_panel.kicad_pcb]
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2026-09-30 子基板 B を 44.6 x 99.5mm に拡大: M3 丸端子台 x6・ヒートシンク固定穴 x2・電源ベタのはんだ盛り
    - 電源 (J3 VIN / J5 GND) と 4 相出力 (J40〜J43) を Würth REDCUBE の M3 丸端子台で受ける
    - ヒートシンク固定用 M3 穴 H1/H2。MOSFET・シャントは BOTTOM 面 (ヒートシンク側) に 4 レッグ横並び
    - 大電流の銅箔を配線前に固定ベタとして置き, レジスト開口ではんだを盛れるようにした
    - 右端の VBUS 帯を表裏 2 層に, レッグ 3 横のネックを裏で迂回, 上端に USB 帰路の GND 帯
    - 電流容量 (1 相): 1oz 5.4A / はんだ 0.3mm 7.4A。USB-PD 経路は 3A まで
    - D1/C1 の −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
    [bom.csv, bridge.kicad_sch, mPBCH32M030DS0_PWR_B.kicad_pcb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]
2026-09-30 MCU モジュール: ピンヘッダを下面実装に (ピンは MCU と反対側), ピン番号を上面シルクに
    - J1/J2 を BOTTOM 面へ裏返した (180° 回転 + 反転で 1 番ピンは上端のまま, 穴の位置は不変)。
    ブレッドボード・子基板のソケットに挿しても USB-C とボタンが上を向き, 操作できる
    - 上面 (MCU 側) の各ピンの外側にピン番号 1〜21, 下面の信号名は樹脂部の外 (1.5mm) へ
    - 配線は確定済みのものをそのまま使う (tools/module_headers_bottom.py)。gen_pcb.py main で作り直す場合も
    配線後に裏返す (flip_after_route)
    - DRC: 電気的エラー 0 / 未接続 0。3D: 単体・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
    [mPBCH32M030DS0.kicad_pcb, mPBCH32M030DS0_panel.kicad_pcb]
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2026-10-02 firmware: FreeRTOS sample with OLED / HT16K33 / TM1640 displays
    - lib: mpb_oled (SSD1306/SH1106 text + bar, non-blocking), mpb_matrix
    (shared 8-row bi-color buffer + marquee), mpb_ht16k33 (I2C chain up to 8),
    mpb_tm1640 (port of TM1640MatrixChain, shared SCLK, parallel DIN), 5x7 font
    - examples/rtos_motor_display: stepper + 4 static tasks on FreeRTOS
    - RTOS: TIM3-based Delay_Us/Ms replace the SysTick-based SDK ones
    - I2C: refuse Start while a finished result is unconsumed (bus sharing)
    - RAM functions moved to .highcode (no assembler section warnings)
    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
    [config.h, mpb_time.c, sketch.c]
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2026-10-02 safety: watchdog (WWDG) with gates-off, shoot-through hardening
    - core/mpb_wdt.c: WWDG (max ~29ms) with early-warning interrupt as a
    software watchdog (MPB_WDT_MS, default 200ms; setup 3s). On timeout or a
    failed bridge safety check: all gates off, then the WWDG resets. If
    interrupts stop, the WWDG resets by itself. Starts on the first feed with
    interrupts enabled (FreeRTOS before the scheduler). Reset cause API.
    - Mpb_Gates_Off(): TIM1 MOE off + PB8..PB15 to GPIO low in one write; called
    at main() entry, overcurrent ISR, HardFault/NMI, reset-to-bootloader,
    RTOS assert / stack overflow / malloc failure
    - bridge: dead time floor MPB_DEAD_MIN_NS (300ns, <200 is a compile error,
    r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
    [config.h, main.c, mpb.h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]
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2026-10-02 dc: braking as one continuous state (regen -> short -> hold -> coast) with VBUS guard
    - mpb_dc: states reduced to COAST / drive / STOP / BRAKE(hold) + fault.
    Mpb_Dc_Stop(m, mA): constant braking current, no plugging; regen strength
    ramps up from 0 and backs off fast near the VBUS limit (default nominal
    + 1V for non-sinking supplies, brake_vbus_max_mV for batteries); jumps to
    short brake once BEMF/R <= current limit (no energy to the bus); holds
    brake_hold_ms then coasts (all FETs off)
    - duty/current decel protection: never drop duty below the current-limit
    floor (no 8A short-brake spike on a duty step to 0); above the VBUS limit
    keep duty just above the BEMF point (deceleration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
    [config.h, mpb.h, sketch.c]
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
